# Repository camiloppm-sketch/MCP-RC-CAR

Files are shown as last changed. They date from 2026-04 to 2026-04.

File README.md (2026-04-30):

📖 Descripción del Proyecto
Este repositorio contiene el diseño, la simulación y la implementación física de un sistema de Control Predictivo Basado en Modelo (MPC) para la dirección lateral de un vehículo autónomo a escala. El "cerebro" matemático fue diseñado y simulado en Simulink/MATLAB, exportado autómaticamente como código C++ mediante MATLAB Coder
, e integrado en un microcontrolador ESP32 para ejecutarse en tiempo real
.
El vehículo es capaz de seguir trayectorias complejas precalculadas (como una figura en forma de "mariposa" de 14,988 waypoints) resolviendo problemas de optimización matricial en bucles fijos de 100 milisegundos
.
⚙️ Metodología y Modelo Físico
El control predictivo asume una velocidad longitudinal constante hacia adelante y ajusta la dinámica lateral utilizando un modelo cinemático de bicicleta. Las constantes físicas fundamentales medidas y utilizadas en el código son:
Distancia entre ejes (L): 0.18 metros
.
Odometría (Velocidad y Posición): Calculada en vivo leyendo las señales de un encoder magnético montado en las llantas traseras. A través de pruebas físicas, calibramos la constante en 0.0002079 metros por pulso
.
🧠 Diseño del Controlador (MPC)
El controlador evalúa el costo de sus acciones basándose en el estado actual (Y y ángulo Yaw) frente a una referencia de trayectoria móvil.
Pesos de la Función de Costo:
Prioridad Máxima (W 
y

 =1): Mantener el error de la posición lateral lo más cercano a cero posible.
Prioridad Menor (W 
yaw

 =0.1): El ángulo de orientación (Yaw). Se permite que el vehículo oscile su ángulo de trompa libremente si eso minimiza el error lateral más rápidamente.
Restricciones de Hardware y Confort:
El cálculo matemático restringe estrictamente la variable Steeringanglerad (Ángulo de volante) entre −π/6 y π/6 radianes (±30 
∘
 ) para no forzar la mecánica del servo
.
La tasa de giro está limitada a ±π/12 radianes por segundo para evitar volantazos bruscos y asegurar la estabilidad.
🗂️ La Trayectoria de la Mariposa
Se generó un entorno de simulación espacial utilizando la herramienta Driving Scenario Designer de MATLAB.
La trayectoria exportada consta de una matriz de 14,988 filas con la estructura: {Tiempo en segundos, Posición Y, Ángulo Yaw}
.
Debido al inmenso tamaño de este arreglo (~180 KB), la matriz fue declarada usando el tipo const float para obligar al microcontrolador a almacenarla directamente en la memoria Flash (4MB), evitando un colapso en la memoria RAM del ESP32
.
El vehículo tarda poco más de 2 minutos (150 segundos) en trazar la figura completa
.
🛠️ Hardware Utilizado
Microcontrolador principal: Tarjeta ESP32 de 32 bits, seleccionada por su alta capacidad de procesamiento matemático capaz de resolver el objeto de optimización matricial mpc.step()
.
Actuador de Dirección: Micro Servomotor SG90 operando a una frecuencia de 50Hz, mapeado con pulsos de entre 500 y 2400 µs y ajustado con retroalimentación negativa
.
Tracción Trasera: Motorreductor de corriente continua JGA25-370 de 12V y 60 RPM con Encoder Integrado de efecto Hall
.
Controlador de Potencia: Módulo Puente H L298N (Conectado a los pines IN3 y IN4 para sentido de giro y recibiendo un PWM constante en ENB)

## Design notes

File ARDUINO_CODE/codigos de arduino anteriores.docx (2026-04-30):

# Código servo

// Creamos el objeto servo

Servo servoDireccion;

// Definimos tu nuevo pin de señal

const int pinServo = 4;

void setup() {

Serial.begin(115200);

// Configuramos la frecuencia estándar para servos (50Hz)

servoDireccion.setPeriodHertz(50);

// Inicializamos el servo usando exactamente tus especificaciones:

// Pin 4, pulso mínimo 500 µs, pulso máximo 2400 µs

servoDireccion.attach(pinServo, 500, 2400);

Serial.println("Iniciando prueba de dirección con Servo SG90 en el Pin 4...");

delay(2000);

}

void loop() {

// 1450 µs es el punto central aproximado (la mitad entre 500 y 2400)

Serial.println("Dirección: CENTRO");

servoDireccion.writeMicroseconds(1450);

delay(2000);

Serial.println("Dirección: IZQUIERDA (Máximo)");

servoDireccion.writeMicroseconds(2400);

delay(2000);

Serial.println("Dirección: CENTRO");

servoDireccion.writeMicroseconds(1450);

delay(2000);

Serial.println("Dirección: DERECHA (Máximo)");

servoDireccion.writeMicroseconds(500);

delay(2000);

}

# Código motor

// 1. DEFINICIÓN DE PINES

const int pinIN3 = 27; // Dirección 1

const int pinIN4 = 26; // Dirección 2

const int pinENB = 19; // NUEVO: Pin de velocidad PWM conectado al ENB

void setup() {

Serial.begin(115200);

// Configurar los pines como salida

pinMode(pinIN3, OUTPUT);

pinMode(pinIN4, OUTPUT);

pinMode(pinENB, OUTPUT);

Serial.println("Iniciando prueba de control de velocidad PWM en pin 19...");

delay(2000);

// Configuramos el motor para girar hacia adelante

digitalWrite(pinIN3, HIGH);

digitalWrite(pinIN4, LOW);

}

void loop() {

Serial.println("Velocidad: LENTA (25%)");

analogWrite(pinENB, 64); // 64 de 255

delay(3000); // Mantiene esta velocidad por 3 segundos

Serial.println("Velocidad: MEDIA (50%)");

analogWrite(pinENB, 127); // 127 de 255

delay(3000);

Serial.println("Velocidad: MÁXIMA (100%)");

analogWrite(pinENB, 255); // 255 es el máximo voltaje

delay(3000);

Serial.println("Motor: DETENIDO");

analogWrite(pinENB, 0); // 0 corta el voltaje (freno)

delay(3000);

}

# Código encoder;

// 1. DEFINICIÓN DE PINES

const int pinEncoder = 34; // Signal B del encoder

const int pinIN3 = 27; // Pin dirección 1 al L298N (Canal B)

const int pinIN4 = 26; // Pin dirección 2 al L298N (Canal B)

volatile long pulsos_totales = 0;

float distancia_recorrida = 0.0;

const float DISTANCIA_POR_PULSO = 0.0002079

// Función de interrupción del encoder

void IRAM_ATTR contarPulsos() {

pulsos_totales++;

}

void setup() {

Serial.begin(115200);

// Configurar pines del motor

pinMode(pinIN3, OUTPUT);

pinMode(pinIN4, OUTPUT);

// Configurar encoder (Cambiado a INPUT normal para evitar el error de hardware y el ruido)

pinMode(pinEncoder, INPUT);

attachInterrupt(digitalPinToInterrupt(pinEncoder), contarPulsos, RISING);

Serial.println("Iniciando prueba de 30 cm. Motor arrancando en 3 segundos...");

delay(3000); // Pausa para que alcances a poner el auto en el suelo

// Encender el motor hacia adelante

digitalWrite(pinIN3, HIGH);

digitalWrite(pinIN4, LOW);

}

void loop() {

// Calcular distancia en tiempo real

distancia_recorrida = pulsos_totales * DISTANCIA_POR_PULSO;

// Imprimir en pantalla

Serial.print("Distancia calculada: ");

Serial.print(distancia_recorrida, 4);

Serial.println(" m");

// ¿Llegamos a los 30 centímetros (0.3 metros)?

if (distancia_recorrida >= 0.3000) {

// ¡FRENAR EL MOTOR! (Freno activo poniendo ambos pines en LOW)

digitalWrite(pinIN3, LOW);

digitalWrite(pinIN4, LOW);

Serial.println("¡Objetivo alcanzado! Verifica con la cinta métrica.");

while(true); // Detener el código aquí para siempre

}

delay(50);

}

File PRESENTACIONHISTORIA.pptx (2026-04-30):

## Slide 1

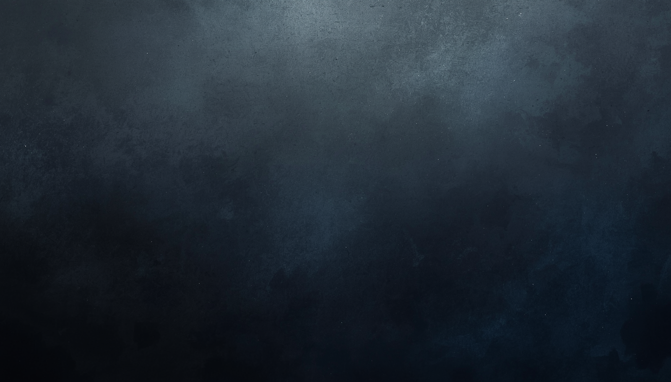
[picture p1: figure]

Presentación desarrollo
vehículo con MPC

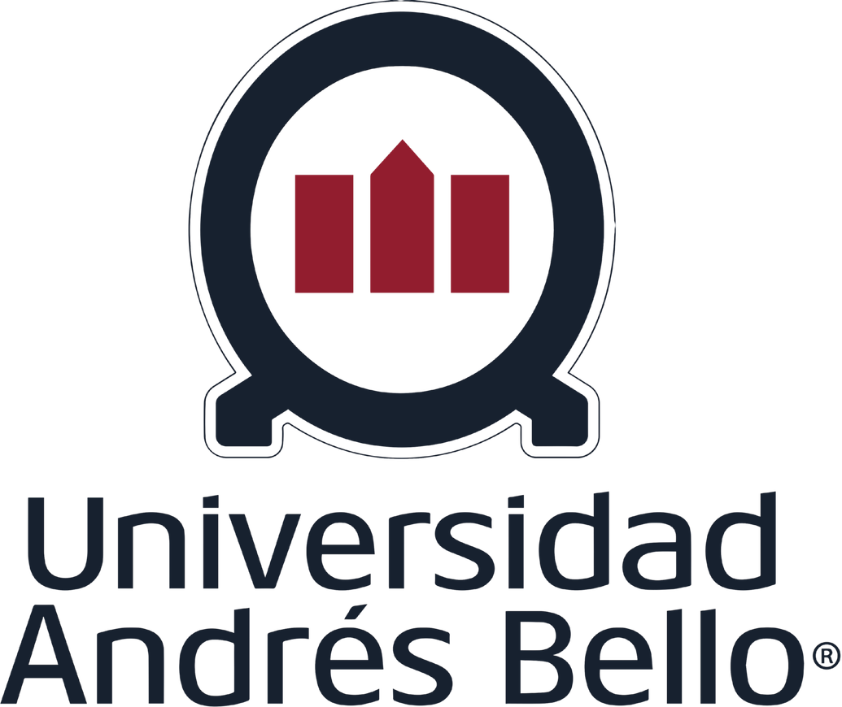
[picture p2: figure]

integrantes:
Gabriel Coronado
Lucas Garay
Camilo Prieto
Vicente Mesias
Mario Acevedo

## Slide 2

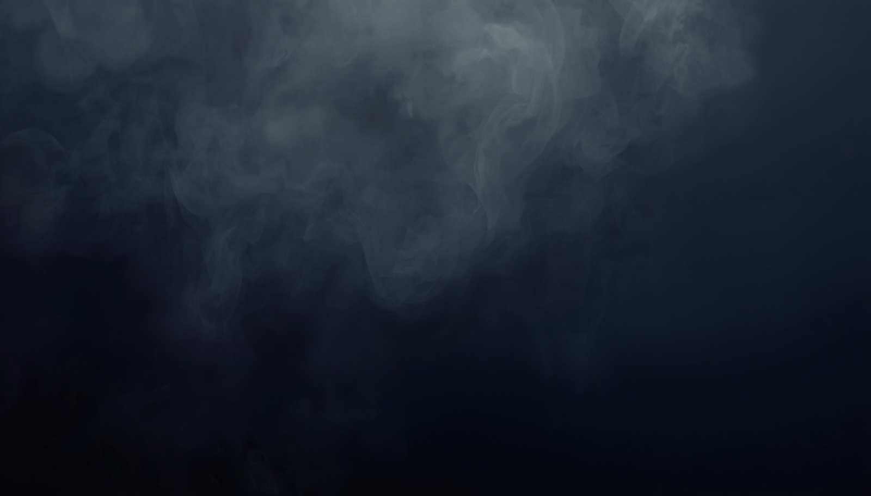
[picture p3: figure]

Etapa 1: selección de hardware

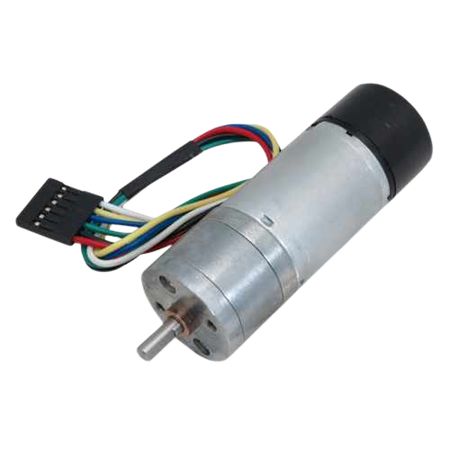
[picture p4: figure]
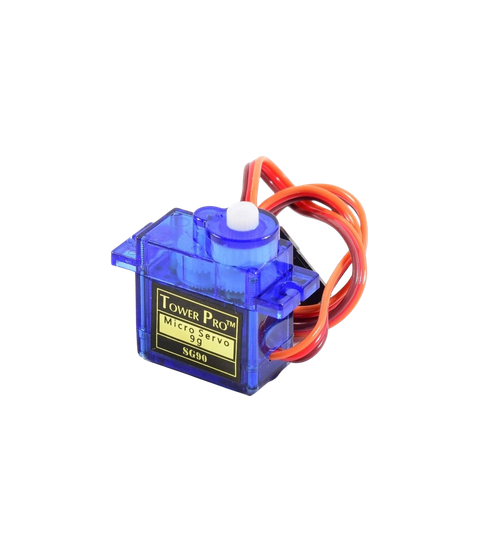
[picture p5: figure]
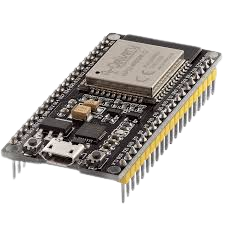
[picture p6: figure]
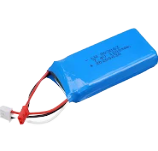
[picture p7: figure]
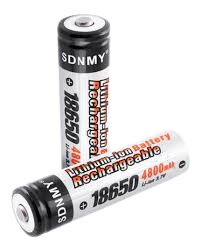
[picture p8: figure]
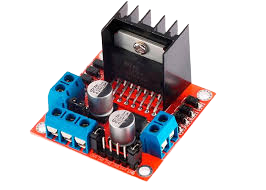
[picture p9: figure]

X 4 = 14 V aprox

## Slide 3

Etapa 2: modelado 3D estructura y piezas

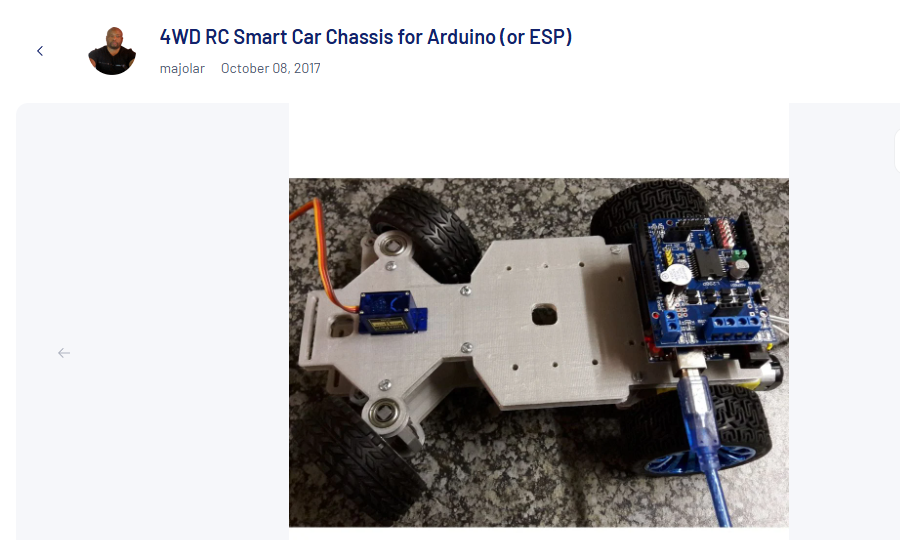
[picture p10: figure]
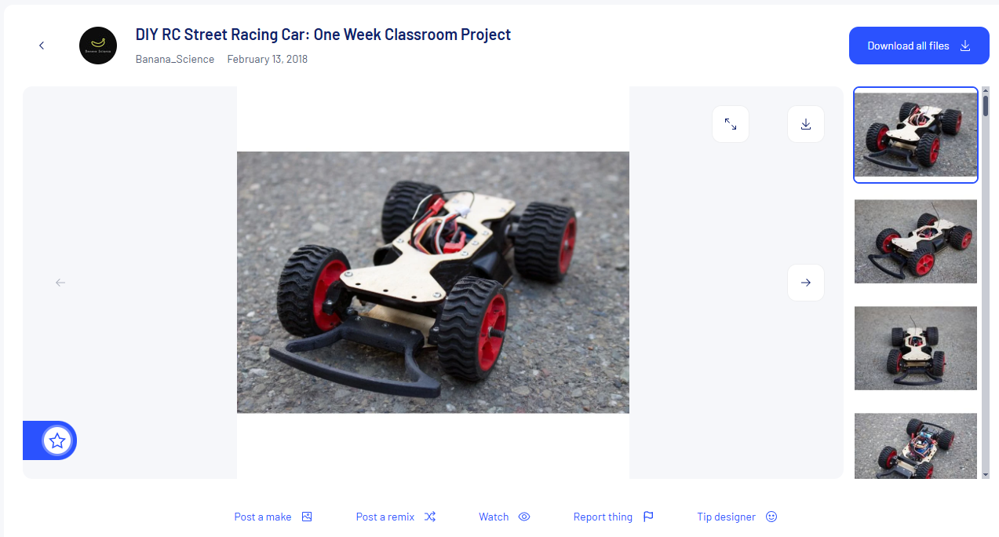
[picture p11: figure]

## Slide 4

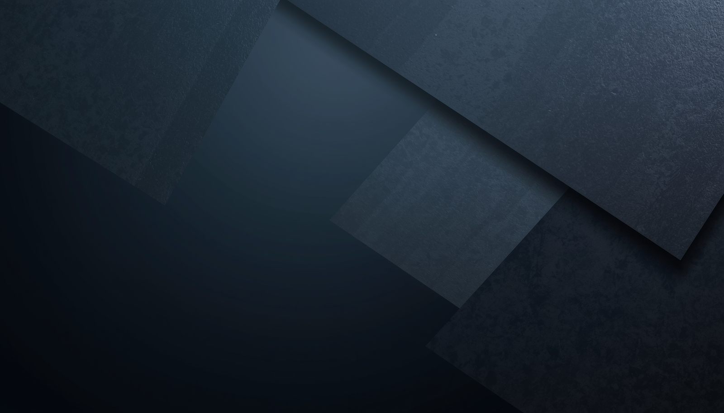
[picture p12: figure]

Etapa 3: Montaje de vehículo

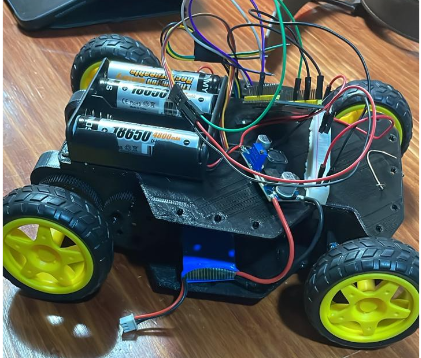
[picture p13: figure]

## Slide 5

Etapa 4: generación referencia y obtención de la planta

Driving scenario simulator

parametros auto

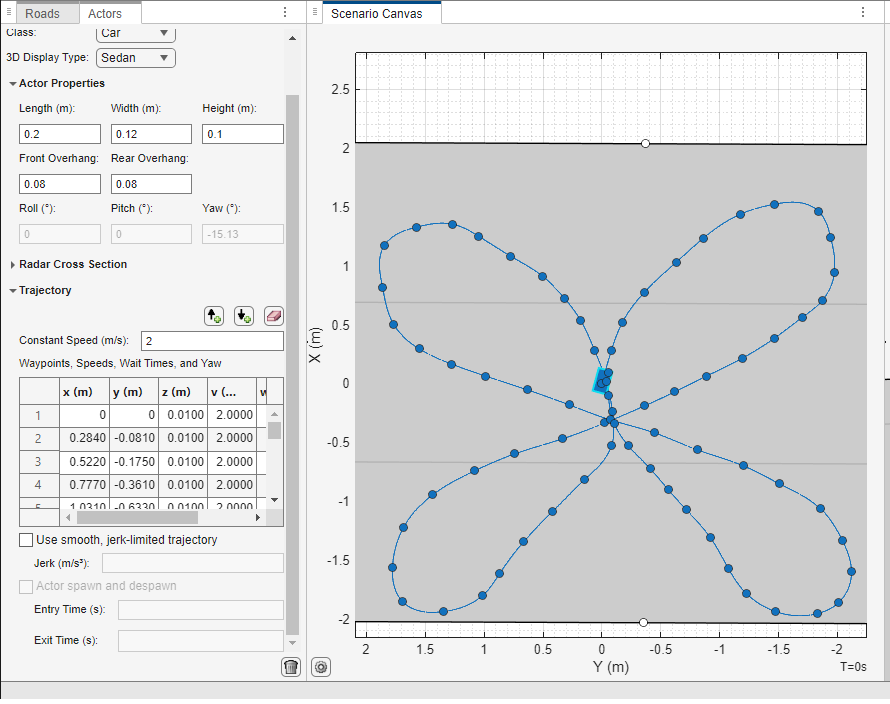
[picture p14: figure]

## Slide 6

Etapa 4: generación referencia y obtención de la planta

matrices de estado y obtención state space

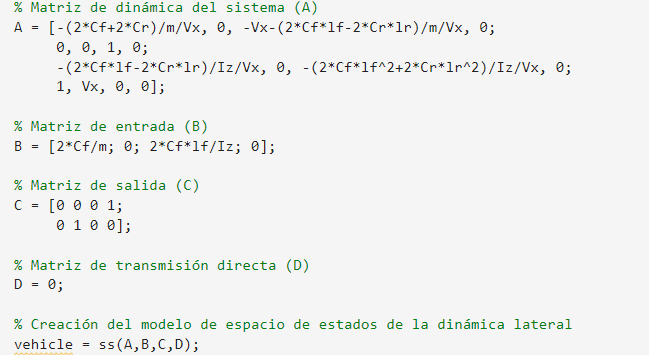
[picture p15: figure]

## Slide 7

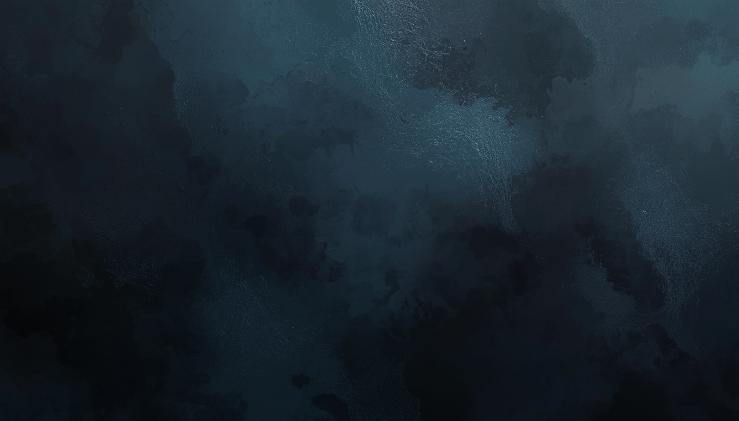
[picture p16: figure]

Etapa 5: lazo de control en Matlab y diseño de MPC

definir weights, constrains, mpc structure, io atributes

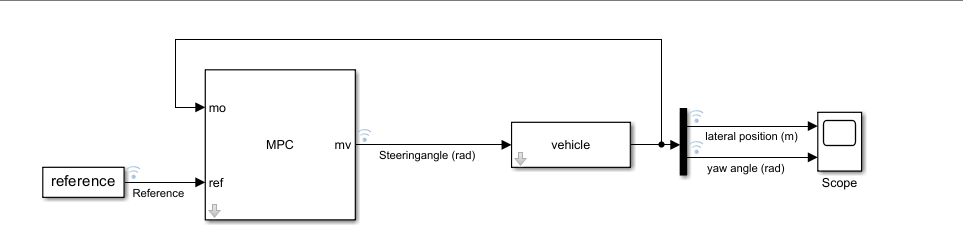
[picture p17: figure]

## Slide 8

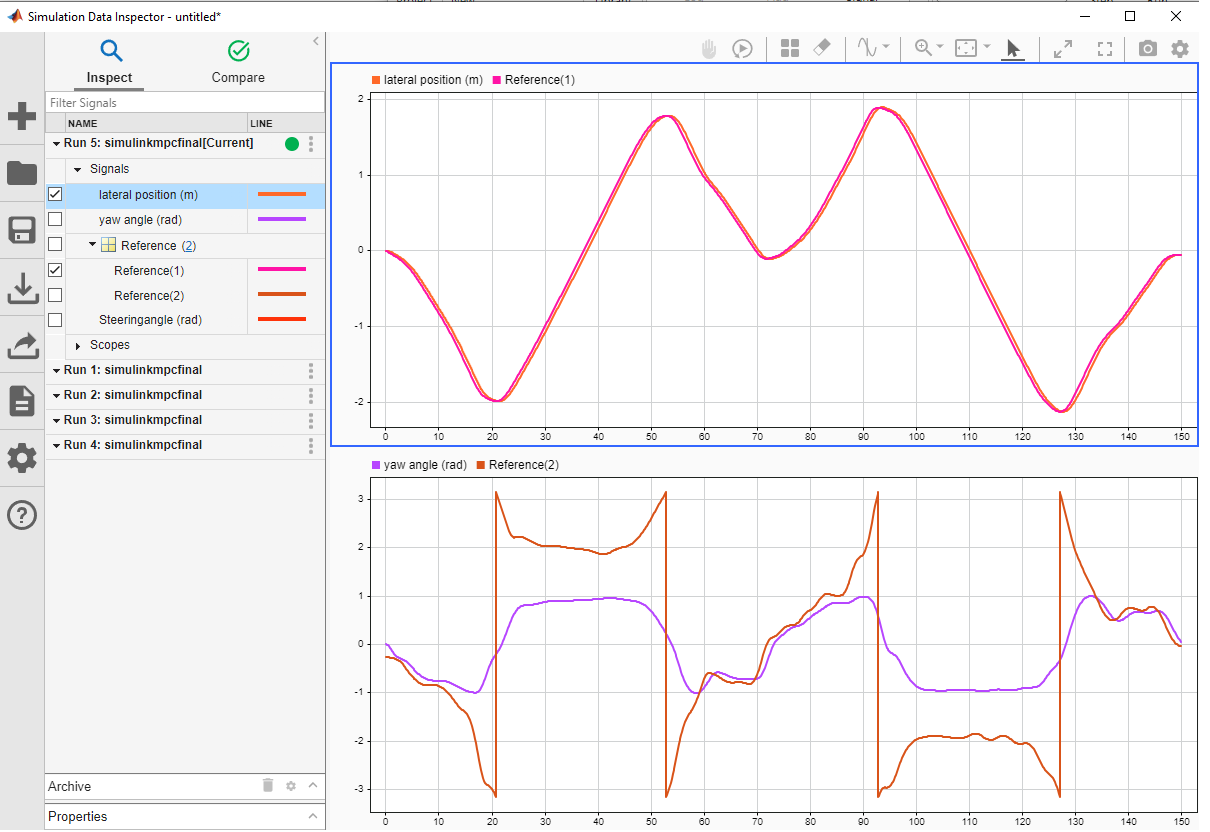
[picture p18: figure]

Etapa 6: resultados simulink para confirmar

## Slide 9

Etapa 7: Exportar a código en arduino con matlab y probar resultados

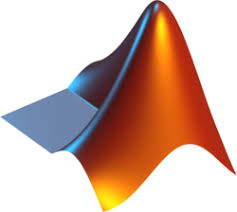
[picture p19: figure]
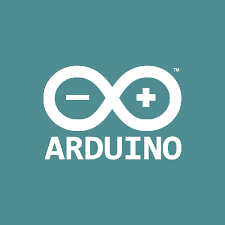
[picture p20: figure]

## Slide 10

En conclusión

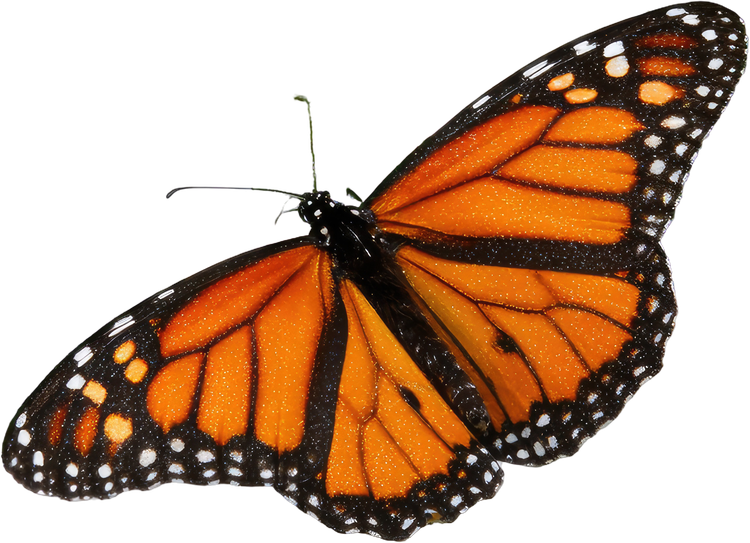
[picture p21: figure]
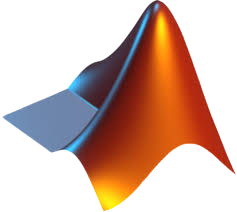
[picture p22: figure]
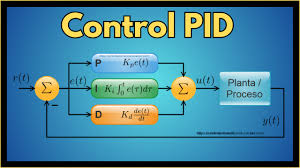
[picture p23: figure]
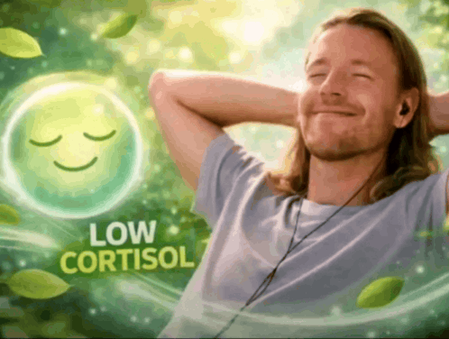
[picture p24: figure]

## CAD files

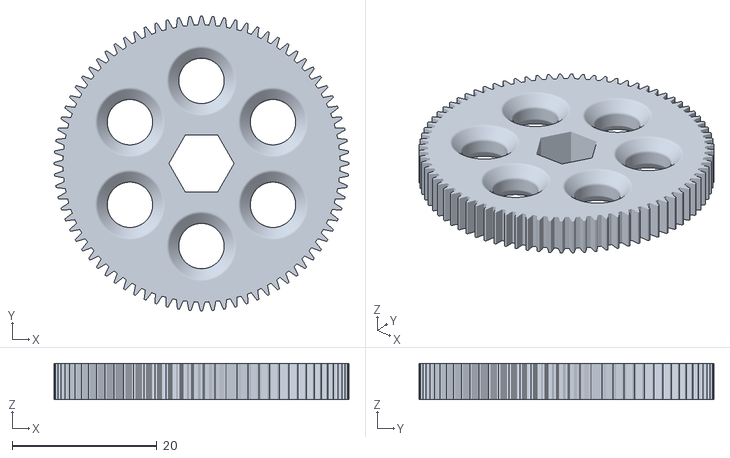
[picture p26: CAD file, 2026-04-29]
3D_MODEL/Rear_Drive_Gear_80T.stl
40.7 x 40.7 x 5.00

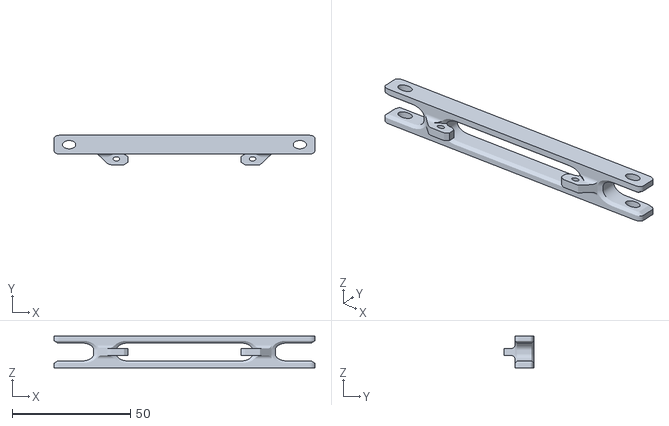
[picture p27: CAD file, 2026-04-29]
3D_MODEL/Steering_-Rack-.stl
110.4 x 12.5 x 13.5

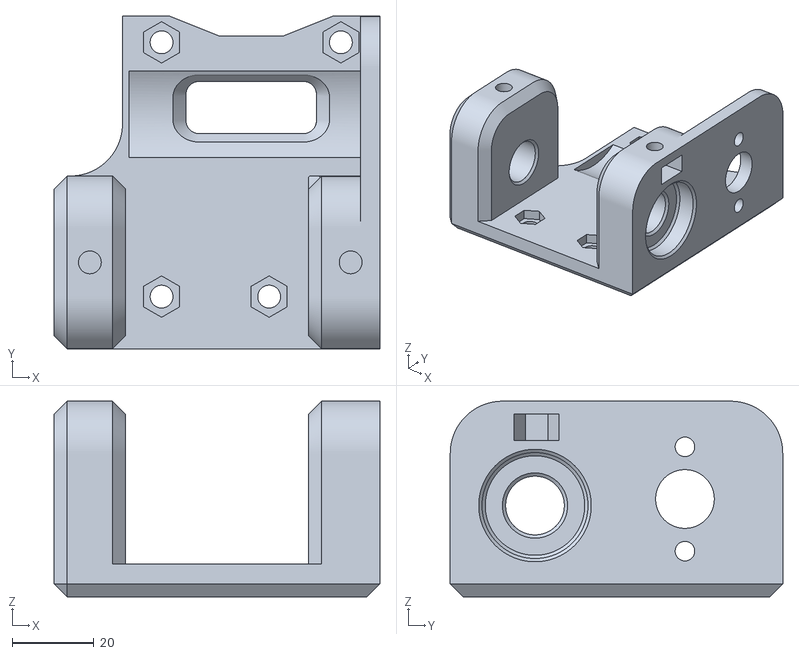
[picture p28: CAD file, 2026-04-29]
3D_MODEL/2430_Motor_MountADJ(1).stl
80.0 x 81.6 x 48.0

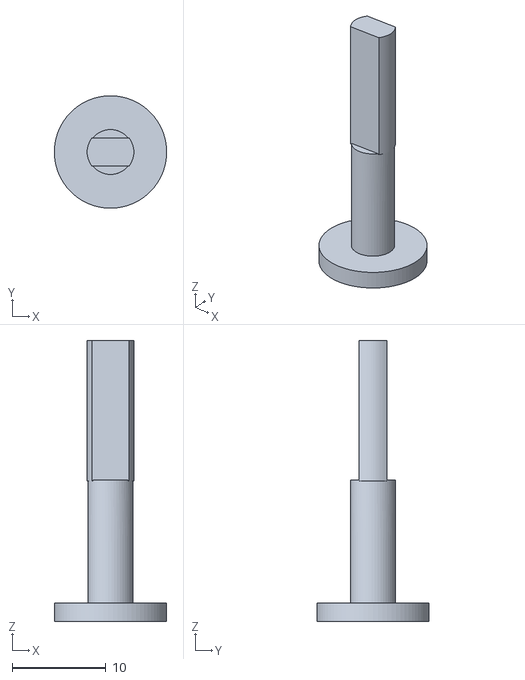
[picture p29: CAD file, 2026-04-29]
3D_MODEL/UnionRueda.stl
12.0 x 12.0 x 30.0

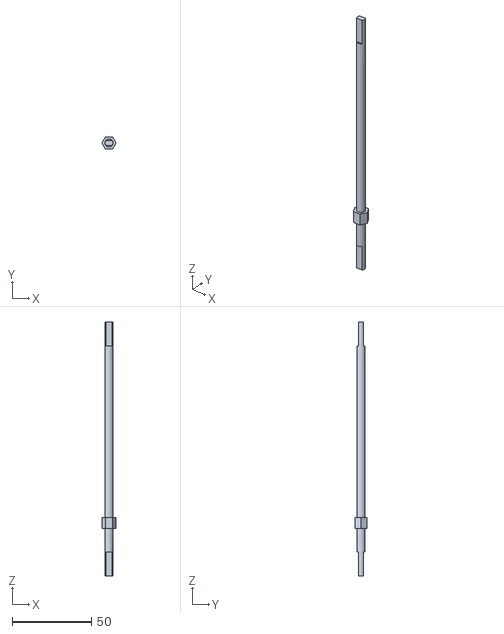
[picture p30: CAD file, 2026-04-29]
3D_MODEL/ejeruedasV2.stl
9.00 x 7.80 x 160.0

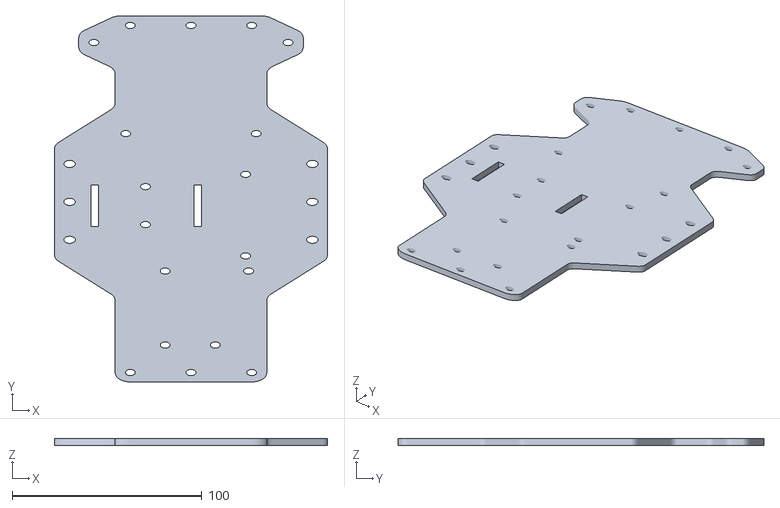
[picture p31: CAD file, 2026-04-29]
3D_MODEL/3D_Printable_Bottom_Plate.stl
144.0 x 193.0 x 3.50

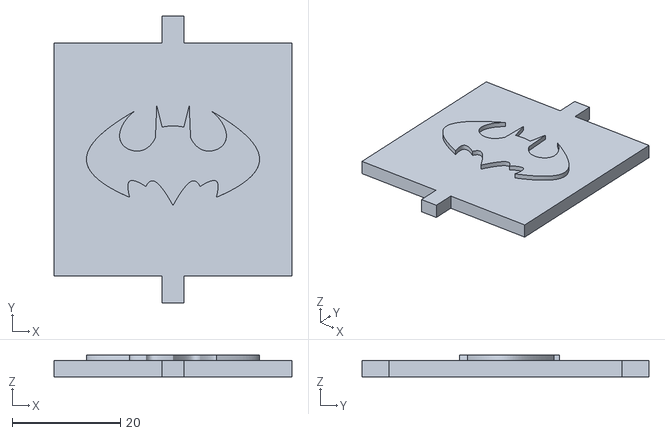
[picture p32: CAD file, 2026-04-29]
3D_MODEL/ParedUnionTechoSuelo.stl
44.0 x 53.0 x 4.00

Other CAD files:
3D_MODEL/MOTOR_GEAR_V3.stl

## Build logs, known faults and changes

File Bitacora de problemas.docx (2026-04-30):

Bitacora de problemas

Referencia de mariposa original muy cerrada y da un trabajo imposible o vías alternativas, se optó por cambiar la referencia a una forma similar

Engranajes no calzaron permitiendo que haya poca eficiencia de energía transformada, a veces se atascaban, rozaban sin mas

Nuestro segundo piso no estaba planeado originalmente, pero nació debido a la necesidad de tener mas epacio para los componentes

Al crear este segundo piso no se pensó en un soporte frontal lo que topaba con las ruedas delanteras, se diseña un soporte estructural en modelado

Al principio se consideraba el uso de una sola fuente de energía luego se optó por 2 para no combinar control con potencia ya que no es recomendados por picos de corriente nominal y posibles daños a controlador esp32

Debido a que no contábamos con imu se tuvo que recurrir al uso de odometria para calcular el angulo de giro del vehículo, el problema es que había que conocer el ppr de los reductores y no estaban en ningún lado para nuestro modelo en esécífico, se hizo experimento con distancia de avance para conocer cada cuanta distancia hay un pulso

En algunas ruedas los ejes no tenían 100% eficiencia de trabajo ya que rozaban no tapaban completamente, se soluciona usando adhesivos

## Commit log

2026-04-30 Modelo simulink MPC para exportar a C
2026-04-30 Modelo MPC simulink para visualización ref
2026-04-30 Funcion de DSD con trayectoria
2026-04-30 Validación encoders, servo y motores pwm
2026-04-30 Código final cargado en la ESP32 para el auto
2026-04-30 Add JGA25 motor manual and purchase links
    Added links for JGA25 motor manual and purchase.
2026-04-30 Librerias de matlab mpc a arduino
2026-04-30 Variable referencia de matlab exportado a arduino
2026-04-30 Bitacora de problemas resumida
